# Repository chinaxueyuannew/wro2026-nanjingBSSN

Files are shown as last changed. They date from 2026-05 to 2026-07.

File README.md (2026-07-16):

# 南京博颂学校 | 2026 WRO Future Engineers 工程材料 / Engineering Materials

> 本页面所有内容均为中文与英文直接对照。 / All content on this page is presented directly in Chinese and English.

本仓库是 **南京博颂学校 / BONA SONORITY SCHOOL NANJING** 参加 2026 WRO Future Engineers 的公开工程材料，沿用官方 Future Engineers 模板，记录底盘、机电集成、Orange Pi视觉与GPIO/PWM直接控制、测试、安全分析、团队资料与演示视频。

This public repository documents the 2026 WRO Future Engineers project of **BONA SONORITY SCHOOL NANJING**. It follows the official Future Engineers template and records the chassis, mechatronic integration, Orange Pi vision with direct GPIO/PWM control, tests, safety analysis, team materials and demonstration video.

车辆以阿克曼四轮驱动底盘为机械基础，只使用 **USB彩色摄像头**进行环境感知。**Orange Pi Zero 3W 4GB**在同一平台上完成视觉、路径决策、安全状态管理和GPIO/PWM执行，直接控制转向舵机与电机驱动器。当前车辆不安装Arduino，不使用超声波，也不读取编码器。

The vehicle uses a four-wheel-drive Ackermann chassis and a **USB colour camera as its only environmental sensor**. An **Orange Pi Zero 3W 4GB** performs vision, path decisions, safety-state management and GPIO/PWM execution on the same platform, directly controlling the steering servo and motor driver. The current vehicle has no Arduino, ultrasonic sensing or encoder feedback.

## 演示视频 / Driving Video

### [▶ YouTube：2026 WRO Future Engineers | 南京博颂学校 | Autonomous Driving Demonstration](https://youtu.be/DJcxiJCEFdo)

南京博颂学校自动驾驶演示 / Autonomous driving demonstration (https://youtu.be/DJcxiJCEFdo)

视频详情、原片参数与版本记录见 [`video视频/video.md`](video视频/video.md)。

See [`video视频/video.md`](video视频/video.md) for video details, local-file specifications and version records.

## 队伍与赛事成果 / Team and Competition

### 南京博颂学校 / BONA SONORITY SCHOOL NANJING

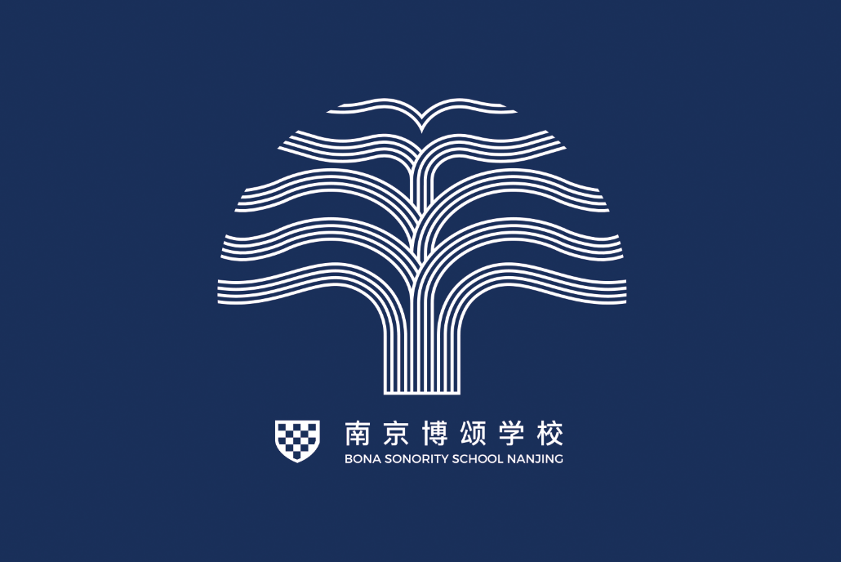
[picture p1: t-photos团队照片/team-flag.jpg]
南京博颂学校队旗 / School flag


我们围绕视觉无人驾驶阿克曼车辆开展程序、结构和电子系统协作。

We collaborate on programming, mechanical structure and electronics for a vision-based autonomous Ackermann vehicle.

| 姓名 / Name | 分工 / Role |
|---|---|
| 陆昭颖 / Lu Zhaoying | 程序 / Programming |
| 张隽泽 / Zhang Junze | 结构 / Mechanical Structure |
| 黄鸣博 / Huang Mingbo | 电子 / Electronics |
| 薛源 / Xue Yuan | 教练 / Coach |

[查看完整团队介绍 / Read the full team profile](other其他/team-profile.md) · [陆昭颖自我介绍（中/英/日） / Lu Zhaoying profile (CN/EN/JP)](other其他/team-profile.md#lu-zhaoying-profile)

### 成员照片 / Member Portraits

| 陆昭颖 / Lu Zhaoying | 张隽泽 / Zhang Junze | 黄鸣博 / Huang Mingbo |
|---|---|---|
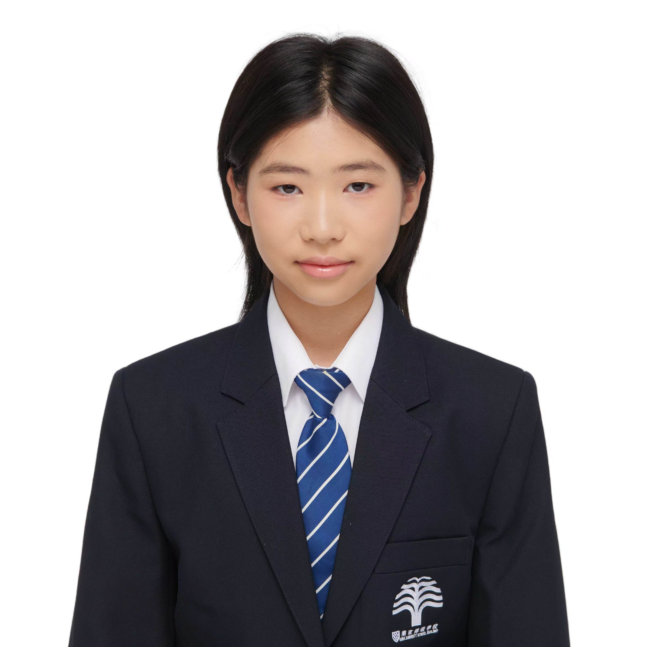
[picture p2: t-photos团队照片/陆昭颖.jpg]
陆昭颖，程序 / Lu Zhaoying, Programming
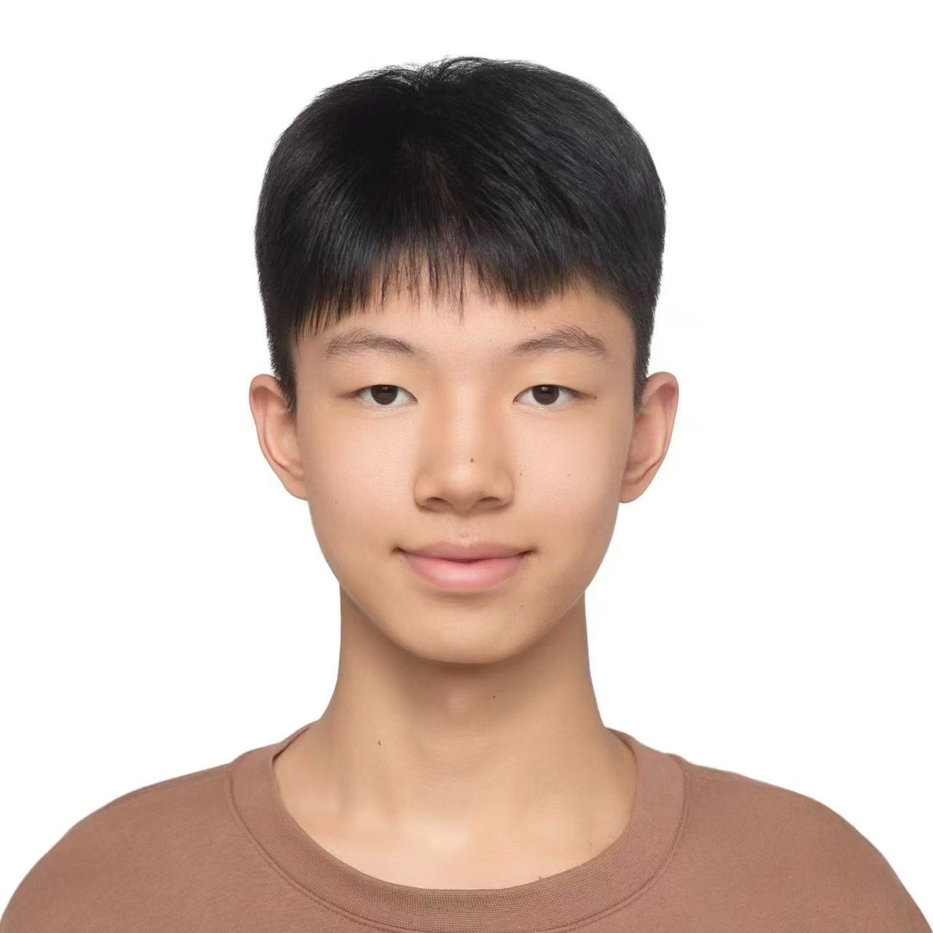
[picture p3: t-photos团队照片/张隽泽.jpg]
张隽泽，结构 / Zhang Junze, Mechanical Structure
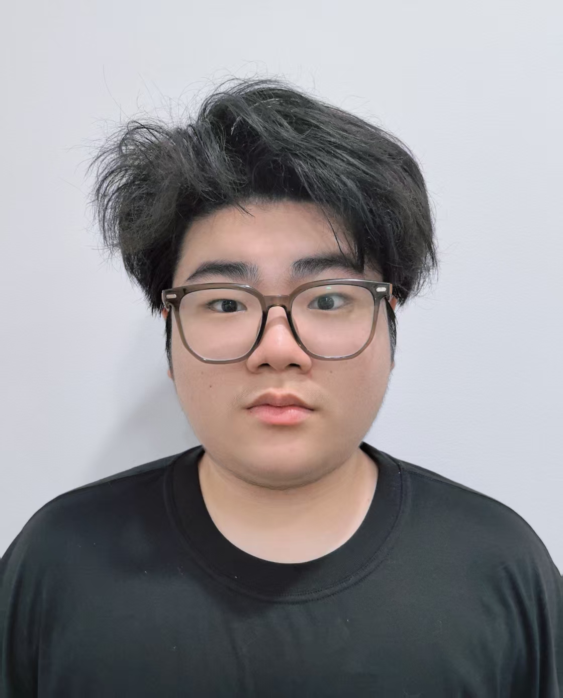
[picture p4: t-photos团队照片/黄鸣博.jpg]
黄鸣博，电子 / Huang Mingbo, Electronics
|  |  |  |

[陆昭颖形象照 / Additional portrait of Lu Zhaoying](t-photos团队照片/陆昭颖形象照.jpg)

### 正式团队照 / Official Team Photograph

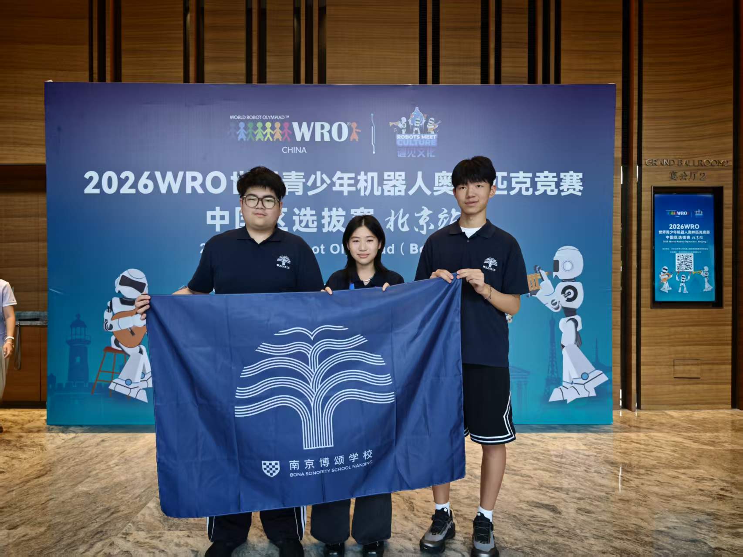
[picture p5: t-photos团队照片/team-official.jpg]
南京博颂学校WRO未来工程师参赛队 / WRO Future Engineers team


### 2026 WRO中国区选拔赛（北京站）未来工程师无人驾驶冠军 / 2026 WRO China Qualification Tournament (Beijing) Future Engineers Autonomous Driving Champion

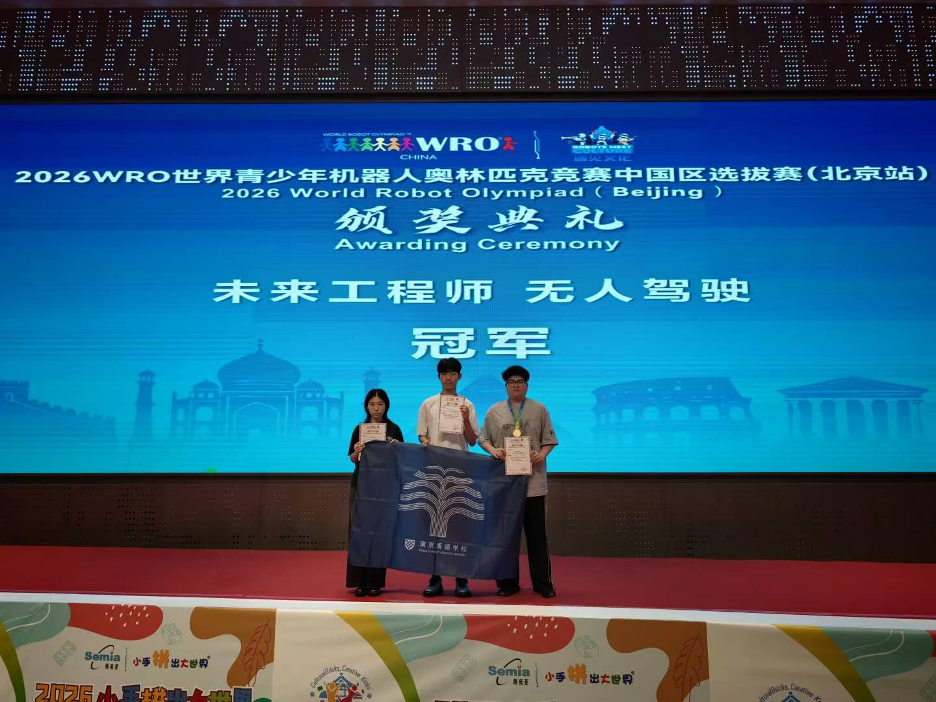
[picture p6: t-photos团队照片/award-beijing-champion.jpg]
北京站冠军领奖照片 / Beijing championship award photograph


### 车辆比赛现场 / Vehicle on the Competition Field

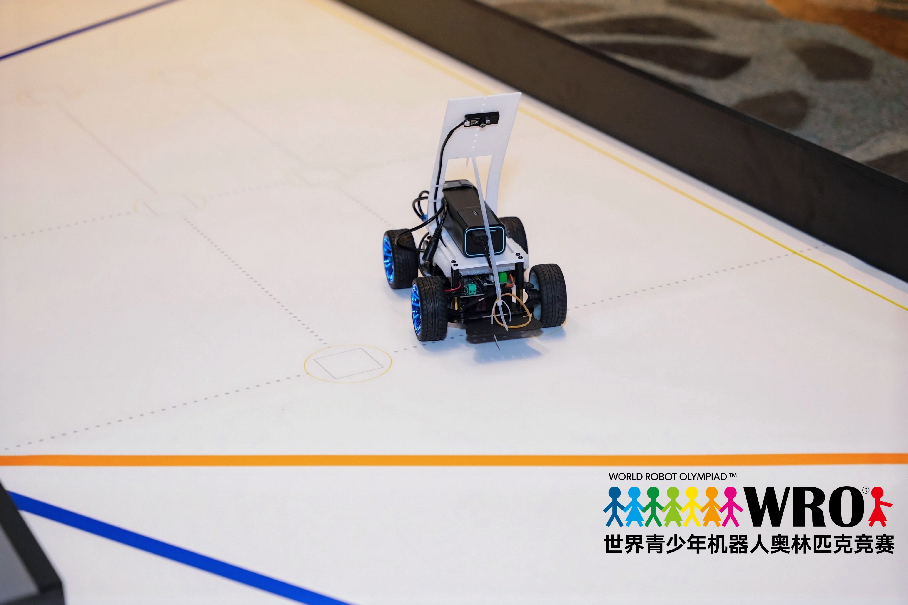
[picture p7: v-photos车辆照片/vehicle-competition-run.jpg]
车辆比赛现场 / Vehicle on the competition field


更多研发记录见[制作过程照片索引](t-photos团队照片/README.md)。车辆标准六视图仍待补充。

See the [development-process photo index](t-photos团队照片/README.md) for more records. The standard six-view vehicle photographs are still pending.

## 快速跳转 / Quick Navigation

- [2026五维评分证据地图 / 2026 rubric evidence map](other其他/scoring-evidence.md) · [可归档工程日志PDF / Archival engineering-log PDF](other其他/engineering-log.pdf) · [实测与照片证据登记 / Evidence register](other其他/evidence-register.md)
- [团队介绍 / Team profile](other其他/team-profile.md) · [系统概述 / System overview](#2-系统概述--system-overview) · [机械设计 / Mechanical design](#3-移动性与机械设计--mobility-and-mechanical-design) · [动力与视觉 / Power and vision](#4-动力与视觉架构--power-and-vision-architecture)
- [源代码 / Source code](src源代码/README.md) · [接线与供电 / Wiring and power](schemes原理图/wiring.md) · [正式PNG接线图 / Formal PNG wiring diagram](schemes原理图/system-wiring.png) · [机械模型 / Mechanical models](models模型/README.md) · [物料表 / BOM](other其他/BOM.md)
- [测试 / Tests](other其他/tests.md) · [工程日志 / Engineering log](other其他/engineering-log.md) · [FMEA](other其他/FMEA.md) · [比赛检查表 / Competition checklist](other其他/competition-checklist.md)
- [团队照片 / Team photos](t-photos团队照片/README.md) · [车辆照片 / Vehicle photos](v-photos车辆照片/README.md) · [视频 / Video](video视频/video.md) · [完整索引 / Complete index](#10-完整文件索引--complete-file-index)

## 当前成果状态 / Current Project Status

| 项目 / Item | 仓库状态 / Repository Status | 验证状态 / Validation Status |
|---|---|---|
| 阿克曼底盘 / Ackermann chassis | 已有机械说明和层板DXF / Mechanical description and plate DXF included | 现有规格记录已整理，最终装车尺寸待测 / Existing specification record documented; final assembled dimensions pending |
| 超声波与编码器代码 / Ultrasonic and encoder code | 团队早期自主实验代码已入库 / Earlier team-developed experimental code included | 当前车辆不使用 / Not used by the current vehicle |
| 道路预处理 / Road preprocessing | `bev_road.py` 已入库 / Included | 透视参数仍需实车标定 / Perspective parameters require vehicle calibration |
| 红绿视觉控制 / Red-green vision control | `bev_segmentation.py` 已入库 / Included | 当前主要方向，仍需板端和实车验证 / Current main approach; board and vehicle validation pending |
| Orange Pi GPIO/PWM执行 / Orange Pi GPIO/PWM execution | `orange_pi_gpio.py`、安全状态机和配置模板已入库 / Driver, safety state machine and configuration template included | 默认禁用、上电停车、物理按钮、限幅、退出清零和250 ms进程看门狗已闭环；实际GPIO/PWM映射及硬件测试待完成 / Disabled-by-default, power-on stop, physical button, limits, zero-on-exit and 250 ms process watchdog implemented; actual mapping and hardware tests pending |
| 接线与配电 / Wiring and distribution | 现行GPIO直控PNG/SVG、供电分支和映射表已入库 / Current direct-GPIO PNG/SVG, power branches and mapping table included | 实际GPIO line、PWM chip/channel、逻辑电平、额定值和支路电流待实物核验 / Actual GPIO lines, PWM chip/channels, logic levels, ratings and branch currents require physical verification |
| 评分与工程日志 / Rubric and engineering log | 五维证据地图、缺失证据登记、双语PDF已入库 / Five-dimension map, gap register and bilingual PDF included | 实测后需更新PDF和签署 / PDF and sign-off require update after measurements |
| 驾驶演示 / Driving demonstration | YouTube链接和87.07 MiB视频已入库 / YouTube link and 87.07 MiB video included | 拍摄日期、提交号和硬件对应表待补 / Date, commit and hardware mapping pending |
| 团队材料 / Team materials | 队旗、介绍、三名成员照、正式照、冠军照和11张过程照已入库 / Flag, profile, three portraits, official photo, award photo and 11 process photos included | 趣味团队照待补 / Informal team photo pending |
| 车辆照片 / Vehicle photos | 比赛现场照片和六视图规范已入库 / Competition photo and six-view specification included | 标准六视图待补 / Standard six views pending |

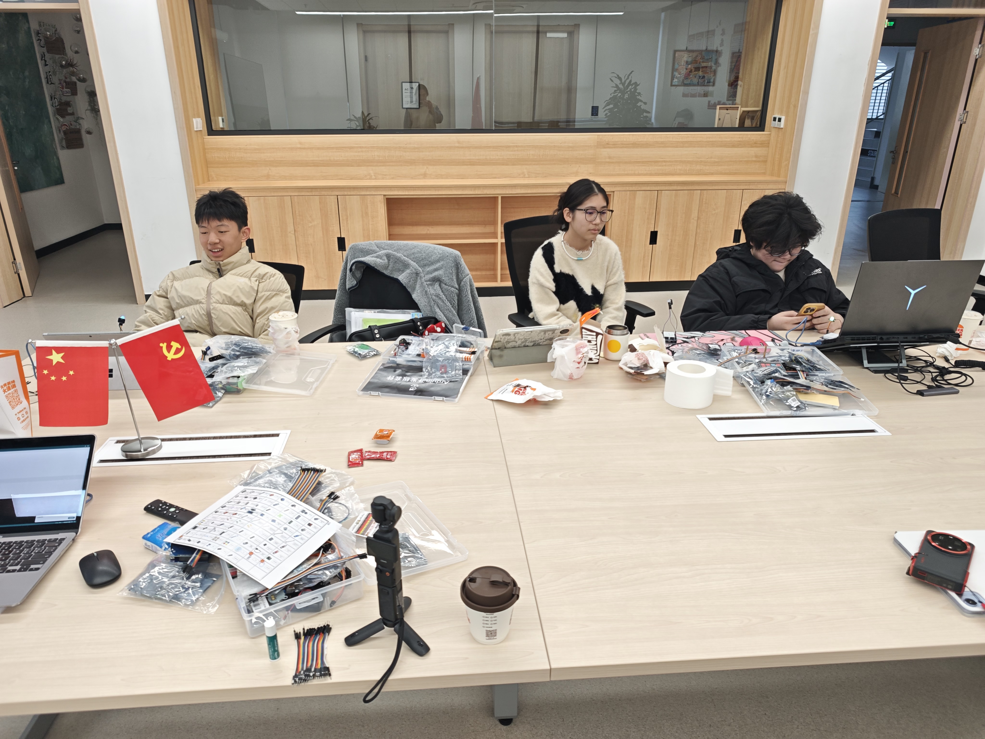
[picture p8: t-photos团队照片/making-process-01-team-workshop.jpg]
团队制作过程 / Team development process


## 1. 仓库导航 / Repository Navigation

| 目录或文件 / Folder or File | 内容 / Contents | 复现用途 / Reproduction Use |
|---|---|---|
| [`README.md`](README.md) | 总体技术说明、视频、状态和导航 / Overall documentation, video, status and navigation | 裁判首页与总体复现 / Landing page and system reproduction |
| [`src源代码/`](src源代码/README.md) | Orange Pi视觉、GPIO/PWM执行与历史实验 / Orange Pi vision, GPIO/PWM execution and historical experiments | 编译、运行和算法审查 / Build, execution and algorithm review |
| [`schemes原理图/`](schemes原理图/wiring.md) | GPIO/PWM映射、供电和接线 / GPIO/PWM mapping, power and wiring | 电气复现 / Electrical reproduction |
| [`models模型/`](models模型/README.md) | 底盘、尺寸和层板DXF / Chassis, dimensions and plate DXF | 机械复现 / Mechanical reproduction |
| [`other其他/`](other其他/engineering-log.md) | 物料、测试、标定、风险和日志 / BOM, tests, calibration, risk and logs | 工程追溯 / Engineering traceability |
| [`t-photos团队照片/`](t-photos团队照片/README.md) | 团队、赛事和制作过程照片 / Team, competition and development photos | 团队与过程证据 / Team and process evidence |
| [`v-photos车辆照片/`](v-photos车辆照片/README.md) | 比赛照片和六视图规范 / Competition photo and six-view specification | 车辆与布线检查 / Vehicle and wiring inspection |
| [`video视频/`](video视频/video.md) | YouTube链接和本地视频参数 / YouTube link and local video specifications | 驾驶证明与版本追溯 / Driving evidence and version traceability |

### 详细工程文件 / Detailed Engineering Documents

- [物料表与选型依据 / Bill of materials and selection](other其他/BOM.md)
- [2026评分证据地图 / 2026 scoring-evidence map](other其他/scoring-evidence.md)
- [实测与照片证据登记 / Measurement and photograph evidence register](other其他/evidence-register.md)
- [源代码、运行方法与验证状态 / Source code, operation and validation](src源代码/README.md)
- [GPIO/PWM接线与供电 / GPIO/PWM wiring and power](schemes原理图/wiring.md)
- [正式PNG接线图 / Formal PNG wiring diagram](schemes原理图/system-wiring.png)
- [机械模型、尺寸与DXF / Mechanical models, dimensions and DXF](models模型/README.md)
- [Orange Pi车载计算平台 / Orange Pi onboard computer](other其他/processor-orange-pi.md)
- [摄像头与视觉方案 / Camera and vision](other其他/camera-vision.md)
- [机械分析 / Mechanical analysis](other其他/mechanical-analysis.md)
- [软件架构 / Software architecture](other其他/software-architecture.md)
- [标定手册 / Calibration guide](other其他/calibration-guide.md)
- [风险分析 / Risk analysis](other其他/FMEA.md)
- [复现指南 / Reproduction guide](other其他/reproduction-guide.md)
- [工程日志Markdown / Engineering log in Markdown](other其他/engineering-log.md) · [可归档PDF / Archival PDF](other其他/engineering-log.pdf)
- [工程日志PDF生成脚本 / Engineering-log PDF build script](other其他/build_engineering_log_pdf.py)
- [团队介绍 / Team profile](other其他/team-profile.md)
- [比赛检查表 / Competition checklist](other其他/competition-checklist.md)
- [测试流程 / Test procedure](other其他/tests.md)
- [版本记录 / Changelog](other其他/CHANGELOG.md)

## 2. 系统概述 / System Overview

车辆采用汽车式阿克曼转向和四轮机械驱动。四根转向拉杆将舵机动作传到左右转向节；前后差速器和中间传动轴驱动车轮。底盘电机带有霍尔编码器接口，但当前车辆不接线、不读取，也不进行闭环速度控制。

The vehicle uses automotive-style Ackermann steering and mechanical four-wheel drive. Four steering links transfer servo motion to the left and right steering knuckles. Front and rear differentials and a longitudinal shaft drive the wheels. The motors provide Hall-encoder interfaces, but the current vehicle does not connect or read them and does not use closed-loop speed control.

底盘规格为 **260 × 140 × 85 mm**；去除防撞棉后主体长度约 **246 mm**。轴距 **174 mm**，轮距 **123 mm**，轮径 **47 mm**，离地间隙 **6 mm**，基础重量约 **0.7 kg**，标称负载 **0.3 kg**，最小转弯半径 **475 mm**。安装全部设备后必须重新实测。

The documented chassis size is **260 × 140 × 85 mm**, or approximately **246 mm** long without the foam bumpers. Wheelbase is **174 mm**, track width **123 mm**, wheel diameter **47 mm**, ground clearance **6 mm**, base mass approximately **0.7 kg**, rated additional load **0.3 kg**, and minimum turning radius **475 mm**. All values must be measured again after final assembly.

```mermaid
flowchart LR
  CAM["USB彩色摄像头 / USB colour camera"] --> OPI["Orange Pi Zero 3W 4GB"]
  OPI -->|"视觉与决策 / Vision and decisions"| SAFE["GPIO安全状态机 / GPIO safety state machine"]
  SAFE -->|"PWM（映射待冻结） / PWM mapping pending"| SERVO["转向舵机 / Steering servo"]
  SAFE -->|"PWM + DIR（映射待冻结） / mapping pending"| DRIVER["电机驱动器 / Motor driver"]
  BUTTON["物理启动/停止按钮 / Physical start-stop"] -->|"3.3 V GPIO input"| SAFE
  DRIVER --> MOTOR["四轮驱动 / Four-wheel drive"]
  BAT["车载电源 / Vehicle battery"] --> REG["稳压与配电 / Regulation and distribution"]
  REG --> OPI
  REG --> SERVO
  REG --> DRIVER
```

当前感知输入只有USB摄像头。视觉帧过期、控制更新过期、程序异常或退出时，Orange Pi输出层必须立即把电机占空比置零并使舵机回中；250 ms进程看门狗触发后必须重新按键授权。该进程级机制不能覆盖Linux内核或硬件PWM整体冻结，因此最终安全评估仍需验证是否增加独立硬件使能门。

The USB camera is the only perception input. On stale frames, stale control updates, exceptions or process exit, the Orange Pi output layer must immediately command zero motor duty and centred steering; a 250 ms process-watchdog event requires physical re-arming. This process-level mechanism cannot cover a complete Linux-kernel or hardware-PWM freeze, so the final safety assessment must determine whether an independent hardware enable gate is required.

## 3. 移动性与机械设计 / Mobility and Mechanical Design

### 3.1 底盘方案 / Chassis Concept

选择阿克曼底盘是因为其运动方式接近真实汽车，直线稳定、转弯轨迹连续且轮胎侧滑较小。代价是转弯半径受轴距和最大转角限制，必须准确标定舵机中位、左右极限和转向连杆。

The Ackermann chassis was selected because its motion resembles a real car, with stable straight-line travel, continuous turning paths and reduced tyre scrub. The trade-off is a turning radius limited by wheelbase and maximum steering angle, so servo centre, left/right limits and steering links require careful calibration.

差速器允许转弯时内外侧车轮以不同速度滚动。最终文档仍需补充实车传动照片、齿数、电机标牌和完整装配尺寸。

The differentials allow inner and outer wheels to rotate at different speeds during a turn. Final documentation still requires drivetrain photographs, gear counts, motor labels and complete assembled dimensions.

### 3.2 转向保护 / Steering Protection

历史程序曾把逻辑转向量 `-100...100` 映射到约 `35...145°`。当前GPIO/PWM输出层为降低首次集成风险，默认使用更保守的舵机脉宽范围与中位脉宽；这些都不是最终装车结论。必须架空实测左右机械安全极限并留出余量，更换舵机、舵臂孔位或拉杆长度后必须重新标定。

Historical sketches mapped logical steering `-100...100` to approximately `35...145°`. To reduce first-integration risk, the current GPIO/PWM output layer uses a conservative default pulse-width range and centre pulse. These are not final assembled-vehicle results; measure both mechanical limits with the wheels lifted and retain margin. Recalibrate after changing the servo, horn position or link length.

### 3.3 速度、扭矩与几何 / Speed, Torque and Geometry

规格图给出47 mm轮径、1:8.864齿轮速比、1692 rpm车轮转速、12 V参考速度3.5 m/s、1.9 A额定电流、22.8 W额定功率和10 kg·cm舵机扭矩。

The catalogue lists a 47 mm wheel diameter, 1:8.864 gear ratio, 1692 rpm wheel speed, 3.5 m/s reference speed at 12 V, 1.9 A rated current, 22.8 W rated power and 10 kg·cm servo torque.

- 理论车速 / Theoretical speed：`v = π × D × n_motor / (60 × i)`
- 轮端扭矩 / Wheel torque：`T_wheel = T_motor × i × η`
- 牵引力 / Traction：`F = T_wheel / (D/2)`
- 阿克曼半径 / Ackermann radius：由轴距、轮距和内轮转角计算，并用地面画圆验证 / calculated from wheelbase, track and inner-wheel angle, then verified by a measured ground circle

1692 rpm按47 mm轮径换算约4.17 m/s，高于3.5 m/s参考值，可能分别是理论空载值和实际参考值，因此两者均保留并要求实测。

At a 47 mm wheel diameter, 1692 rpm converts to approximately 4.17 m/s, above the 3.5 m/s reference. These may represent theoretical no-load and practical reference values respectively, so both are retained and require measurement.

## 4. 动力与视觉架构 / Power and Vision Architecture

### 4.1 控制器与执行器 / Controllers and Actuators

Orange Pi负责摄像头、OpenCV图像处理、赛道判断、红绿障碍策略、安全状态机以及GPIO/PWM输出。它通过内核PWM直接控制舵机和电机速度，通过3.3 V GPIO控制电机方向并读取物理启动/停止按钮。实际GPIO line和PWM chip/channel必须依据冻结的比赛系统镜像、设备树与实物排针核对后填写，文档不虚构引脚号。

The Orange Pi handles the camera, OpenCV processing, track interpretation, red/green obstacle strategy, safety state machine and GPIO/PWM output. Kernel PWM directly controls steering and motor speed; 3.3 V GPIO controls motor direction and reads the physical start/stop button. Actual GPIO lines and PWM chip/channel values must be filled only after checking the frozen competition image, device tree and physical header; this documentation does not invent pin numbers.

舵机和电机不得由Orange Pi排针供电。应使用电机动力支路、Orange Pi独立5 V/3 A稳压支路和舵机独立支路，并保持控制共地。连接驱动器前必须确认其逻辑输入兼容3.3 V；不兼容时使用合适的电平转换或接口电路。

The servo and motor must not be powered from the Orange Pi header. Use a motor-power branch, an independent regulated 5 V/3 A Orange Pi branch and a separate servo branch, with a common control ground. Confirm 3.3 V compatibility before connecting the driver; otherwise use an appropriate level shifter or interface circuit.

### 4.2 视觉感知 / Vision Perception

车辆只安装一个USB彩色摄像头，不安装超声波，也不读取编码器。团队采购记录中的版本为 **160°广角有畸变、30 FPS彩色、非夜视、480p**，并记录GC0308、HBVCAM、CMOS、30万像素和USB免驱。彩色画面用于区分红绿障碍；广角畸变通过标定、ROI裁剪和现场光照测试处理。

The vehicle uses one USB colour camera, with no ultrasonic sensors and no encoder readings. The team purchase record identifies a **160° distorted wide angle, 30 FPS colour, non-night-vision and 480p** version and records GC0308, HBVCAM, CMOS, 0.3 megapixels and driver-free USB. Colour frames distinguish red and green obstacles; wide-angle distortion is handled through calibration, ROI cropping and on-site lighting tests.

安全措施包括配置默认禁用、上电默认停车、视觉帧超时、250 ms控制更新看门狗、程序退出清零PWM、物理启动/停止控制、方向切换前先归零电机以及最坏停车距离测试。

Safety measures include disabled-by-default configuration, stopped-by-default power-up, vision-frame timeout, a 250 ms control-update watchdog, zero PWM on exit, physical start/stop control, zero motor duty before direction changes and worst-case stopping-distance tests.

### 4.3 动力预算 / Power Budget

总峰值电流应按下式估算，并用实车电流数据替换目录值：

Total peak current should be estimated with the following expression and updated using measured vehicle data:

`I_peak = I_motor_start + I_servo_stall + I_orange_pi_camera + I_controller + safety_margin`

测试应记录静止、视觉运行、直行、最大转向和电机启动时的电池电压与电流。复位、摄像头断连或掉帧时，应检查稳压余量、共地、电机噪声和线束压降。

Tests must record battery voltage and current while idle, running vision, travelling straight, steering fully and starting the motor. If a controller resets or the camera disconnects or drops frames, check regulator margin, common ground, motor noise and wiring voltage drop.

## 5. 软件架构与控制策略 / Software Architecture and Control Strategy

### 5.1 当前程序 / Current Programs

| 层级 / Layer | 程序 / Program | 内容 / Function | 状态 / Status |
|---|---|---|---|
| 历史巡墙基线 / Historical wall-follow baseline | [`main1.0.ino`](src源代码/main1.0/main1.0.ino) | 双超声波P控制 / Dual-ultrasonic P control | 当前不使用 / Not currently used |
| 团队早期实验 / Earlier team experiments | [`UNO_AT8236`](src源代码/UNO_AT8236_OpenChallenge/UNO_AT8236_OpenChallenge.ino), [`UNO_DRV8701`](src源代码/UNO_DRV8701_OpenChallenge/UNO_DRV8701_OpenChallenge.ino) | 编码器PI和双超声波 / Encoder PI and dual ultrasonic | 团队自主开发，当前不使用 / Team-developed; not currently used |
| ESP32试验 / ESP32 experiment | [`ESP32_AT8236`](src源代码/ESP32_AT8236_OpenChallenge/ESP32_AT8236_OpenChallenge.ino) | AT8236控制和关闭无线 / AT8236 control and wireless shutdown | 仅参考 / Reference only |
| 道路工具 / Road tool | [`bev_road.py`](src源代码/bev_road.py) | 亮度、BEV、道路掩膜和连通域 / Brightness, BEV, road mask and components | 需实车标定 / Vehicle calibration required |
| 视觉与策略 / Vision and strategy | [`bev_segmentation.py`](src源代码/bev_segmentation.py) | 红绿识别、方向策略、恢复和GPIO输出调用 / Red-green detection, direction strategy, recovery and GPIO-output calls | 当前主要方向 / Current main approach |
| Orange Pi GPIO/PWM执行 / Orange Pi GPIO/PWM execution | [`orange_pi_gpio.py`](src源代码/orange_pi_gpio.py) | 物理按钮、PWM/DIR输出、限幅、250 ms看门狗和安全释放 / Physical button, PWM/DIR output, limits, 250 ms watchdog and safe release | 语法通过；实际映射和实车验证待完成 / Syntax passed; actual mapping and vehicle validation pending |
| 上一版串口执行 / Previous serial executor | [`VisionSerialExecutor.ino`](src源代码/VisionSerialExecutor/VisionSerialExecutor.ino) | Arduino串口执行架构的历史记录 / Historical record of the Arduino serial-execution architecture | 当前不安装、不运行 / Not installed or run currently |

当前三份Python核心文件已通过语法解析。视觉程序默认速度为0，减速阈值低于避障阈值，制动阶段先停车，并在视频源丢失或程序退出时调用安全停止。`orange_pi_gpio.py`将直接硬件访问集中在一个输出层：配置默认 `enabled=false`，只有填写并核验真实映射后才打开GPIO/PWM；上电进入 `WAIT_START`，由物理按钮授权，250 ms无新控制更新进入 `CONTROL_FAILSAFE`，异常或退出时电机归零、舵机回中并释放资源。该实现仍需在冻结系统镜像上完成设备树、PWM占用、3.3 V逻辑兼容性、输出波形和整车停车测试。

The three current core Python files pass syntax parsing. The vision controller defaults to zero speed, keeps the slow-down threshold below the avoidance threshold, stops before recovery braking and invokes a safe stop on video loss or process exit. `orange_pi_gpio.py` centralises direct hardware access in one output layer: `enabled=false` is the default, GPIO/PWM is opened only after real mappings are entered and verified, power-up enters `WAIT_START`, a physical button arms motion, no fresh control update for 250 ms enters `CONTROL_FAILSAFE`, and exceptions or exit zero the motor, centre steering and release resources. Device-tree exposure, PWM ownership, 3.3 V logic compatibility, output waveforms and full-vehicle stopping still require verification on the frozen competition image.

历史Arduino程序中的 `getDistance()`、`move()`、`steer()`、`setup()` 和 `loop()` 仅用于解释早期硬件验证，不代表当前传感器配置。

The `getDistance()`, `move()`, `steer()`, `setup()` and `loop()` functions in historical Arduino programs document early hardware validation only and do not represent the current sensor configuration.

### 5.2 历史巡墙控制 / Historical Wall-Following Control

早期程序使用目标右距30 cm、`KP=2.5`和速度70的P控制。该方案计算量小，但不能识别颜色，也缺少积分和微分作用。它仅作为研发历史保留。

The early program used a 30 cm target right-wall distance, `KP=2.5` and speed 70. It was computationally simple but could not identify colours and had no integral or derivative action. It is retained only as development history.

### 5.3 当前边界与升级 / Current Boundaries and Upgrades

当前版本不使用板间串口。视觉策略在同一进程内调用受限的GPIO/PWM输出接口，并以单调时钟记录最近一次控制更新；物理启动和250 ms进程级失效停车已在代码中实现。透视、HSV、道路密度、红绿通过侧、倒车时间、速度、实际GPIO/PWM映射、停车区、圈数、方向初始化、无桌面自动启动/恢复和多光照长时间测试仍需完成。由于视觉与执行位于同一Orange Pi，Linux或硬件PWM整体冻结是尚未由进程看门狗覆盖的残余风险。

The current version has no inter-board serial link. The vision strategy calls a bounded GPIO/PWM output interface in the same process, using a monotonic clock for the latest control update; physical arming and a 250 ms process-level fail-safe are implemented in code. Perspective, HSV, road density, red/green passing side, reversing time, speed, actual GPIO/PWM mapping, parking, lap counting, direction initialisation, headless startup/recovery and long-duration multi-lighting tests remain incomplete. Because vision and execution share one Orange Pi, a complete Linux or hardware-PWM freeze remains outside the process watchdog's coverage.

## 6. 系统思维与工程决策 / System Thinking and Engineering Decisions

1. **阿克曼转向 / Ackermann steering：** 更接近汽车并提高直线稳定性，但需要更精确的机械标定。 / More automotive and stable in straight travel, but requires more precise mechanical calibration.
2. **历史超声波基线 / Historical ultrasonic baseline：** 曾用于验证底盘、舵机和电机方向；当前只保留代码，不作为比赛传感器或安全备份。 / Previously validated chassis, servo and motor direction; retained only as code history, not as a competition sensor or safety backup.
3. **视觉失效停车 / Stop on vision failure：** 无独立距离传感器时，视觉帧或控制更新超时必须立即把电机PWM置零并要求重新授权。 / Without an independent range sensor, a vision-frame or control-update timeout must immediately set motor PWM to zero and require re-arming.
4. **单板直控取舍 / Single-board direct-control trade-off：** 取消Arduino和串口可减少器件、线束与协议延迟，但视觉、决策和执行进入同一故障域，因此必须明确进程看门狗的边界并评估独立硬件使能保护。 / Removing the Arduino and serial link reduces parts, wiring and protocol latency, but places vision, decision and execution in one fault domain; the process-watchdog boundary and an independent hardware enable must therefore be assessed explicitly.

## 7. 搭建、编译与上传 / Assembly, Build and Upload

1. 按[机械文档](models模型/README.md)固定底盘、Orange Pi、电源、摄像头、舵机和支架；当前车辆不安装Arduino。 / Mount the chassis, Orange Pi, power system, camera, servo and brackets according to the [mechanical documentation](models模型/README.md); the current vehicle has no Arduino.
2. 在冻结的比赛镜像上列出 `/dev/gpiochip*` 与 `/sys/class/pwm`，对照排针和设备树确认真实GPIO line、PWM chip/channel及复用关系。 / On the frozen competition image, enumerate `/dev/gpiochip*` and `/sys/class/pwm`, then confirm real GPIO lines, PWM chip/channels and pin multiplexing against the header and device tree.
3. 按[接线文档](schemes原理图/wiring.md)连接摄像头、物理按钮、舵机与电机驱动器；先确认3.3 V逻辑兼容并保持负载独立供电与控制共地。 / Follow the [wiring guide](schemes原理图/wiring.md) for the camera, physical button, servo and motor driver; verify 3.3 V logic compatibility and keep load power separate with a common control ground.
4. 安装并冻结Python、OpenCV、NumPy和python-periphery依赖，把 [`gpio_config.example.json`](src源代码/gpio_config.example.json) 复制为本地 `gpio_config.json`，核验后再把 `enabled` 设为 `true`。 / Install and freeze Python, OpenCV, NumPy and python-periphery, copy [`gpio_config.example.json`](src源代码/gpio_config.example.json) to local `gpio_config.json`, and set `enabled` to `true` only after verification.
5. 保持 `enabled=false` 用录像测试视觉与DRY_RUN输出，确认默认速度为0、方向与红绿策略正确。 / Keep `enabled=false` while testing vision and DRY_RUN output from recordings; confirm zero default speed and correct direction and red/green strategy.
6. 抬轮执行G-01至G-10，测量PWM频率、占空比、舵机脉宽、方向切换死区和250 ms看门狗停车时间。 / With the wheels lifted, perform G-01 through G-10 and measure PWM frequency, duty cycle, steering pulse widths, direction-change dead time and the 250 ms watchdog stop time.
7. 从低速开始测试直行、弯道、障碍、摄像头断开、进程终止、重启和30分钟稳定性。 / Starting at low speed, test straight travel, turns, obstacles, camera loss, process termination, restart and 30-minute stability.
8. 在[测试记录](other其他/tests.md)中保存日期、提交号、镜像版本、映射、参数和结果。 / Record date, commit, image version, mapping, parameters and results in the [test records](other其他/tests.md).

## 8. 测试、风险与版本管理 / Testing, Risk and Version Management

主要风险包括舵机顶死、电机启动压降、视觉误判或掉帧、摄像头断开、GPIO/PWM映射错误、3.3 V逻辑不兼容、Linux或PWM冻结、转向符号错误、线束松脱、轮胎打滑、上电即行驶和无线通信未关闭。每次上场前应完成静态、抬轮、低速和完整回合测试。

Main risks include servo mechanical stall, motor-start voltage drop, visual misclassification or dropped frames, camera disconnection, incorrect GPIO/PWM mapping, incompatible 3.3 V logic, a Linux or PWM freeze, reversed steering sign, loose wiring, tyre slip, movement immediately after power-up and wireless communication left enabled. Complete static, lifted-wheel, low-speed and full-lap tests before every run.

后续提交说明应可追溯，例如 `docs: add measured power budget`、`vision: tune obstacle HSV from field data` 和 `hardware: add final wiring diagram`。公开仓库应按规则保持可访问。

Future commit messages should be traceable, for example `docs: add measured power budget`, `vision: tune obstacle HSV from field data` and `hardware: add final wiring diagram`. The public repository must remain accessible as required by the rules.

## 9. 提交前缺口清单 / Pre-Submission Gap Checklist

- [x] 公开YouTube驾驶演示 / Public YouTube driving demonstration.
- [x] Orange Pi视觉/GPIO直控程序、配置模板以及上一版本Arduino/ESP32实验记录 / Orange Pi vision/direct-GPIO code, configuration template and previous Arduino/ESP32 experiment records.
- [x] DXF、BOM、接线、风险、标定、测试和复现资料 / DXF, BOM, wiring, risk, calibration, test and reproduction materials.
- [x] 2026五维评分地图、缺失证据登记和结构化双语工程日志PDF / 2026 five-dimension map, missing-evidence register and structured bilingual engineering-log PDF.
- [x] Orange Pi GPIO/PWM安全输出层与现行PNG/SVG接线图 / Orange Pi GPIO/PWM safety-output layer and current PNG/SVG wiring diagram.
- [x] 正式团队照、冠军照和比赛现场车辆照 / Official team, championship and competition-field vehicle photographs.
- [ ] 补充车辆前、后、左、右、顶、底六视图 / Add front, rear, left, right, top and bottom vehicle views.
- [ ] 补充全员趣味照 / Add an informal full-team photograph.
- [ ] 在视频文档填写拍摄日期、提交号和硬件参数 / Add recording date, commit and hardware parameters to the video document.
- [ ] 补充最终CAD/STL、传动参数和摄像头安装尺寸 / Add final CAD/STL, drivetrain data and camera mounting dimensions.
- [ ] 以实物核验PNG电路图中的准确器件型号、额定值、逻辑电平、保险和引脚 / Physically verify exact models, ratings, logic levels, fuse and pins in the PNG diagram.
- [ ] 完成尺寸、质量、速度、电流、转弯半径和完整回合实测 / Measure dimensions, mass, speed, current, turning radius and full-lap time.
- [ ] 验证物理启动、视觉/控制更新超时停车、Linux/PWM冻结边界并关闭无线 / Verify physical start, vision/control-update timeout stopping, Linux/PWM freeze boundary and disabled wireless functions.
- [ ] 完成透视、红绿识别、圈数、停车区和停车策略 / Complete perspective, red-green detection, lap counting, parking zone and stopping strategy.

## 10. 完整文件索引 / Complete File Index

### 程序与配置 / Programs and Configuration

| 文件 / File | 内容 / Contents |
|---|---|
| [`src源代码/README.md`](src源代码/README.md) | 运行、依赖、安全和验证状态 / Operation, dependencies, safety and validation status |
| [`main1.0.ino`](src源代码/main1.0/main1.0.ino) | 历史超声波巡墙 / Historical ultrasonic wall following |
| [`UNO_AT8236`](src源代码/UNO_AT8236_OpenChallenge/UNO_AT8236_OpenChallenge.ino) | UNO + AT8236历史参考 / Historical reference |
| [`UNO_DRV8701`](src源代码/UNO_DRV8701_OpenChallenge/UNO_DRV8701_OpenChallenge.ino) | UNO + DRV8701历史参考 / Historical reference |
| [`ESP32_AT8236`](src源代码/ESP32_AT8236_OpenChallenge/ESP32_AT8236_OpenChallenge.ino) | ESP32试验参考 / ESP32 experimental reference |
| [`bev_road.py`](src源代码/bev_road.py) | 道路掩膜和BEV调试 / Road mask and BEV debugging |
| [`bev_segmentation.py`](src源代码/bev_segmentation.py) | 红绿视觉、方向策略、恢复和GPIO输出调用 / Red-green vision, direction strategy, recovery and GPIO output calls |
| [`orange_pi_gpio.py`](src源代码/orange_pi_gpio.py) | 现行GPIO/PWM输出、安全状态和250 ms进程看门狗 / Current GPIO/PWM output, safety states and 250 ms process watchdog |
| [`gpio_config.example.json`](src源代码/gpio_config.example.json) | 默认禁用的GPIO/PWM配置模板 / Disabled-by-default GPIO/PWM configuration template |
| [`VisionSerialExecutor.ino`](src源代码/VisionSerialExecutor/VisionSerialExecutor.ino) | 上一版本Arduino串口执行记录 / Previous Arduino serial-executor record |
| [`requirements.txt`](src源代码/requirements.txt) | Python依赖 / Python dependencies |
| [`serial_config.example.json`](src源代码/serial_config.example.json) | 上一版本串口配置记录 / Previous-version serial configuration record |

### 机械、电气与工程文档 / Mechanical, Electrical and Engineering Documents

| 文件 / File | 内容 / Contents |
|---|---|
| [`models模型/README.md`](models模型/README.md) | 底盘、尺寸和模型 / Chassis, dimensions and models |
| [`HSP94182层板.dxf`](models模型/HSP94182层板.dxf) | 二维层板文件 / 2D plate file |
| [`wiring.md`](schemes原理图/wiring.md) | GPIO/PWM映射、供电和接线 / GPIO/PWM mapping, power and wiring |
| [`system-wiring.png`](schemes原理图/system-wiring.png) / [`SVG`](schemes原理图/system-wiring.svg) | 双语系统接线图与可编辑矢量源 / Bilingual system wiring and editable vector source |
| [`BOM.md`](other其他/BOM.md) | 物料与选型 / Materials and selection |
| [`processor-orange-pi.md`](other其他/processor-orange-pi.md) | Orange Pi规格、职责和验收 / Orange Pi specifications, role and acceptance |
| [`camera-vision.md`](other其他/camera-vision.md) | 摄像头、安装、标定和指标 / Camera, mounting, calibration and metrics |
| [`mechanical-analysis.md`](other其他/mechanical-analysis.md) | 几何、速度和机械分析 / Geometry, speed and mechanical analysis |
| [`software-architecture.md`](other其他/software-architecture.md) | 架构、状态机和数据流 / Architecture, state machine and data flow |
| [`calibration-guide.md`](other其他/calibration-guide.md) | 舵机、摄像头、速度和转向标定 / Servo, camera, speed and steering calibration |
| [`FMEA.md`](other其他/FMEA.md) | 风险与改进 / Risks and improvements |
| [`reproduction-guide.md`](other其他/reproduction-guide.md) | 完整复现流程 / Complete reproduction process |
| [`team-profile.md`](other其他/team-profile.md) | 学校、成员、照片和职责 / School, members, portraits and roles |
| [`engineering-log.md`](other其他/engineering-log.md) | 研发阶段和实验计划 / Development stages and experiment plan |
| [`engineering-log.pdf`](other其他/engineering-log.pdf) | 规则要求的结构化可归档双语工程日志 / Structured archival bilingual engineering log required by the rules |
| [`scoring-evidence.md`](other其他/scoring-evidence.md) | 五维评分要求到证据的映射 / Mapping from the five rubric dimensions to evidence |
| [`evidence-register.md`](other其他/evidence-register.md) | 实测、照片和提交缺口登记 / Measurement, photograph and submission gap register |
| [`commit-plan.md`](other其他/commit-plan.md) | 有意义提交的建议拆分 / Recommended grouping for meaningful commits |
| [`competition-checklist.md`](other其他/competition-checklist.md) | 文件、机械、电气和软件检查 / File, mechanical, electrical and software checks |
| [`tests.md`](other其他/tests.md) | 静态、动力、视觉和故障测试 / Static, power, vision and fault tests |
| [`CHANGELOG.md`](other其他/CHANGELOG.md) | 版本迭代 / Version history |

### 照片与视频 / Photographs and Video

- [YouTube自动驾驶演示 / YouTube autonomous-driving demonstration](https://youtu.be/DJcxiJCEFdo) · [视频资料 / Video documentation](video视频/video.md)
- [学校队旗 / School flag](t-photos团队照片/team-flag.jpg) · [正式团队照 / Official team photo](t-photos团队照片/team-official.jpg) · [冠军照 / Award photo](t-photos团队照片/award-beijing-champion.jpg) · [比赛车辆 / Competition vehicle](v-photos车辆照片/vehicle-competition-run.jpg)
- [制作过程照片 / Development-process photographs](t-photos团队照片/README.md) · [车辆照片要求 / Vehicle photograph requirements](v-photos车辆照片/README.md)

## 信息来源 / Sources

- WRO官方Future Engineers模板 / WRO official Future Engineers template：<https://github.com/world-robot-olympiad-association/wro2022-fe-template>
- 团队底盘资料 / Team chassis reference：<https://pjfcckenlt.feishu.cn/wiki/WlCXwfJRCixkGPkZvTIcfUI6nHg>
- 团队提供的2026比赛规则和技术文档评分要求 / 2026 competition rules and technical-document rubric supplied by the team.

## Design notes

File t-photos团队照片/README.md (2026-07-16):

# 团队、赛事成果与制作过程照片 / Team, Competition and Development Photographs

本目录记录南京博颂学校 WRO Future Engineers 队伍的正式团队照、2026 WRO中国区选拔赛（北京站）冠军领奖照，以及控制器装配、接线、编程、讨论和调试阶段的真实制作过程。11张过程照片统一使用 `making-process-XX-内容.jpg` 命名，便于裁判从仓库首页直接查看并追溯研发过程。

This folder contains the official team photograph, the 2026 WRO China Qualification Tournament (Beijing) championship photograph and eleven authentic development-process photographs covering assembly, wiring, programming, discussion and testing.

## 学校队旗 / School Flag

南京博颂学校队旗 / Bona Sonority School Nanjing flag

- 学校 / School：南京博颂学校 / **BONA SONORITY SCHOOL NANJING**
- 完整团队介绍 / Full team profile：[`other其他/team-profile.md`](../other其他/team-profile.md)

## 团队与赛事成果 / Team and Competition Results

| 内容 Content | 文件 File | 状态 Status |
|---|---|---|
| 正式团队照：三名队员与校旗合影 / Official photograph of all three members with the school flag | [`team-official.jpg`](team-official.jpg) | 已完成 / Complete |
| 北京站未来工程师无人驾驶冠军领奖照 / Beijing Future Engineers Autonomous Driving championship photograph | [`award-beijing-champion.jpg`](award-beijing-champion.jpg) | 已完成 / Complete |
| 陆昭颖正式成员照 / Formal portrait of Lu Zhaoying | [`陆昭颖.jpg`](陆昭颖.jpg) | 已完成 / Complete |
| 陆昭颖形象照 / Additional portrait of Lu Zhaoying | [`陆昭颖形象照.jpg`](陆昭颖形象照.jpg) | 已完成 / Complete |
| 张隽泽正式成员照 / Formal portrait of Zhang Junze | [`张隽泽.jpg`](张隽泽.jpg) | 已完成 / Complete |
| 黄鸣博正式成员照 / Formal portrait of Huang Mingbo | [`黄鸣博.jpg`](黄鸣博.jpg) | 已完成 / Complete |
| 全员趣味团队照 / Informal team photograph | `team-funny.jpg` | 待补充 / Pending |

南京博颂学校正式团队照

南京博颂学校北京站冠军领奖照

## 成员照片 / Member Portraits

| 陆昭颖 / Lu Zhaoying | 张隽泽 / Zhang Junze | 黄鸣博 / Huang Mingbo |
|---|---|---|
| 陆昭颖正式成员照 / Formal portrait of Lu Zhaoying | 张隽泽正式成员照 / Formal portrait of Zhang Junze | 黄鸣博正式成员照 / Formal portrait of Huang Mingbo |

### 陆昭颖形象照 / Additional Portrait of Lu Zhaoying

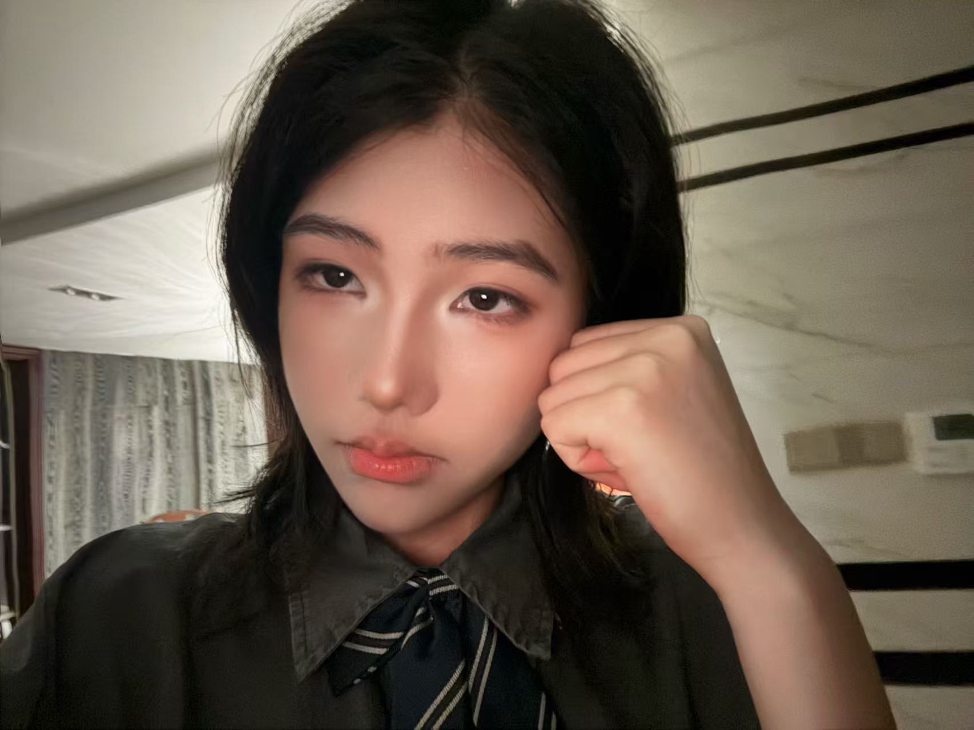
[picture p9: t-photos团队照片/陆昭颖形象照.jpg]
陆昭颖形象照 / Additional portrait of Lu Zhaoying


[陆昭颖自我介绍（中/英/日） / Lu Zhaoying profile (CN/EN/JP)](../other其他/team-profile.md#lu-zhaoying-profile)

## 制作过程照片索引 / Development Process Index

| 编号 No. | 制作环节 Development Activity | 文件 File |
|---:|---|---|
| 01 | 团队研发工作现场 / Team engineering workshop | [`making-process-01-team-workshop.jpg`](making-process-01-team-workshop.jpg) |
| 02 | 软件、硬件与任务讨论 / Software, hardware and task discussion | [`making-process-02-software-discussion.jpg`](making-process-02-software-discussion.jpg) |
| 03 | 控制器连接与硬件调试 / Controller connection and hardware debugging | [`making-process-03-hardware-debug.jpg`](making-process-03-hardware-debug.jpg) |
| 04 | 控制板与连接线装配 / Controller and wiring assembly | [`making-process-04-controller-assembly.jpg`](making-process-04-controller-assembly.jpg) |
| 05 | 底盘和控制模块检查 / Chassis and control-module inspection | [`making-process-05-chassis-check.jpg`](making-process-05-chassis-check.jpg) |
| 06 | 控制器与执行器接线实验 / Controller and actuator wiring | [`making-process-06-controller-wiring.jpg`](making-process-06-controller-wiring.jpg) |
| 07 | 控制板与电子零件调试 / Controller and electronic-component debugging | [`making-process-07-parts-debug.jpg`](making-process-07-parts-debug.jpg) |
| 08 | 程序运行与响应检查 / Program execution and response check | [`making-process-08-program-debug.jpg`](making-process-08-program-debug.jpg) |
| 09 | 程序逻辑与运行结果检查 / Code and result review | [`making-process-09-code-review.jpg`](making-process-09-code-review.jpg) |
| 10 | 根据测试结果修改软件 / Software revision based on tests | [`making-process-10-software-test.jpg`](making-process-10-software-test.jpg) |
| 11 | 控制器功能测试 / Controller functional test | [`making-process-11-controller-test.jpg`](making-process-11-controller-test.jpg) |

## 首页展示图 / Landing-page Image

南京博颂学校团队制作过程

## 规则要求的团队照 / Required Team Photographs

- [x] `team-official.jpg`：全体参赛队员正面、清晰、背景整洁 / all members visible clearly in a formal photograph;
- [ ] `team-funny.jpg`：全体参赛队员入镜的趣味照片 / an informal photograph including all members.

后续趣味团队照应确保所有参赛队员均清晰入镜，同时避免公开不必要的个人隐私。

The future informal team photograph should show every member clearly while avoiding unnecessary disclosure of personal information.

## 团队分工 / Team Roles

| 角色 Role | 主要职责 Main Responsibilities | 姓名 Name |
|---|---|---|
| 程序 / Programming | Orange Pi视觉、算法、GPIO控制、调试与测试日志 / vision, algorithms, GPIO control, tuning and test logs | 陆昭颖 / Lu Zhaoying |
| 结构 / Mechanical Structure | 底盘、摄像头支架、CAD、装配与尺寸复核 / chassis, camera mount, CAD, assembly and dimensional checks | 张隽泽 / Zhang Junze |
| 电子 / Electronics | 供电、Orange Pi GPIO接口、电机驱动、舵机和线束 / power, Orange Pi GPIO interfaces, motor driver, steering servo and wiring | 黄鸣博 / Huang Mingbo |
| 教练 / Coach | 项目指导、安全审查、测试计划与比赛准备 / guidance, safety review, test planning and competition preparation | 薛源 / Xue Yuan |

角色可以协作和重叠，但每名队员都应能解释整车的基本工作原理和本人负责部分。

Roles may overlap through collaboration, but every member should be able to explain the vehicle's basic operation and their own contribution.

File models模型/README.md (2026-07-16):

# 机械模型与尺寸 / Mechanical Models and Dimensions

**当前配置：** 最终装配只需要摄像头视觉支架，不需要超声波支架或编码器信号线。

**Current configuration:** The final assembly requires only a camera mount for vision, with no ultrasonic mounts or encoder signal wiring.

基础机械平台为阿克曼四驱底盘。已确认结构包括前轮舵机转向、四根转向拉杆、四轮驱动、前后差速器、中间传动轴和带霍尔编码器接口的电机。当前只使用电机驱动功能，编码器接口不接线。当前版本由顶部Orange Pi通过GPIO/PWM直接控制舵机和电机驱动器；底板上的UNO安装孔仅是底盘原有孔位，不代表当前安装Arduino。

The mechanical platform is a four-wheel-drive Ackermann chassis. Confirmed features include servo-operated front-wheel steering, four steering links, four-wheel drive, front and rear differentials, a longitudinal driveshaft and motors with Hall-encoder interfaces. Only motor drive is currently used; encoder signals are not connected. In the current version, the upper Orange Pi controls the steering servo and motor driver directly through GPIO/PWM. UNO mounting holes on the lower plate are inherited chassis features and do not indicate that an Arduino is currently installed.

## 团队确认的尺寸与性能 / Team-Confirmed Dimensions and Performance

| 项目 / Item | 数值 / Value |
|---|---:|
| 整车外形 / Overall size | 260 × 140 × 85 mm |
| 去防撞棉主体长度 / Body length without foam bumpers | 246 mm |
| 轴距 / Wheelbase | 174 mm |
| 轮距 / Track width | 123 mm |
| 车轮直径 / Wheel diameter | 47 mm |
| 离地间隙 / Ground clearance | 6 mm |
| 基础重量 / Base mass | 0.7 kg |
| 标称附加载荷 / Rated additional load | 0.3 kg |
| 最小转弯半径 / Minimum turning radius | 475 mm |
| 标称爬坡角 / Rated climbing angle | Below 20° / 小于20° |

安装主控、电池、摄像头和支架后，应重新测量总长、总宽、总高和总质量。

After mounting the controllers, battery, camera and brackets, remeasure overall length, width, height and mass.

本目录中的 `HSP94182层板.dxf` 是可编辑二维CAD文件，可用于层板加工和孔位复核。最终装车后必须逐项核对文件几何与实际层板；当前不宣称它已经是最终比赛版本。

The editable 2D CAD file `HSP94182层板.dxf` supports plate manufacturing and hole-position verification. Its geometry must be checked against the actual plate after final assembly; it is not yet claimed as the final competition version.

## 正式提交前待补 / Items Required Before Final Submission

- 底盘俯视尺寸图：轴距、轮距、轮径、总长、总宽和总高。 / Top-view dimension drawing: wheelbase, track, wheel diameter, overall length, width and height.
- 摄像头支架CAD/STL、距地高度和俯仰角。 / Camera-mount CAD/STL, height above ground and pitch angle.
- 控制板、电池和稳压模块固定件。 / Mounts for controllers, battery and regulators.
- 舵机中位、拉杆孔位和最大安全转角。 / Servo centre, linkage holes and maximum safe steering angle.
- 最终装配图和物料表。 / Final assembly drawing and bill of materials.
- 文件单位、加工方向、材料和紧固件规格。 / File units, manufacturing orientation, materials and fastener specifications.

不要用未经实测的商品页面数据代替最终参赛车辆尺寸。

Do not substitute unmeasured product-page data for final competition-vehicle dimensions.

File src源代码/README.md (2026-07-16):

# 程序说明 / Source Code Guide

> 本文所有内容均为中英直接对照。 / All content is presented in direct Chinese-English pairs.

**现行方案：** `bev_road.py`负责道路/鸟瞰调试，`bev_segmentation.py`负责摄像头、赛道与红绿障碍识别、方向策略和控制循环，`orange_pi_gpio.py`在Orange Pi上直接执行GPIO/PWM输出。当前车辆不安装Arduino，不使用板间串口，不连接超声波，也不读取编码器。

**Current approach:** `bev_road.py` provides road and bird's-eye-view debugging, `bev_segmentation.py` handles the camera, track and red-green obstacle perception, direction strategy and control loop, and `orange_pi_gpio.py` directly executes GPIO/PWM outputs on the Orange Pi. The current vehicle has no Arduino, inter-board serial link, ultrasonic sensors or encoder readings.

## 1. 文件地图 / File Map

| 文件 / File | 平台 / Platform | 功能 / Function | 当前状态 / Current Status |
|---|---|---|---|
| [`bev_road.py`](bev_road.py) | Orange Pi / Python | 亮度、BEV、道路掩膜、连通域和调试图 / Brightness, BEV, road mask, connected components and debug views | 语法通过；透视点待实车标定 / Syntax passed; perspective points require calibration |
| [`bev_segmentation.py`](bev_segmentation.py) | Orange Pi / Python | 红绿识别、方向策略、恢复、仪表板和控制循环 / Red-green detection, direction strategy, recovery, dashboard and control loop | 语法通过；板端与实车待验证 / Syntax passed; board and vehicle tests pending |
| [`orange_pi_gpio.py`](orange_pi_gpio.py) | Orange Pi / Python | GPIO按钮与方向、PWM速度与舵机、状态机和看门狗 / GPIO button and direction, PWM speed and steering, state machine and watchdog | 语法通过；真实映射和波形待验证 / Syntax passed; real mapping and waveforms pending |
| [`gpio_config.example.json`](gpio_config.example.json) | Orange Pi | 默认禁用的GPIO/PWM配置模板 / Disabled-by-default GPIO/PWM configuration template | 所有硬件映射为 `-1`，防止误动作 / All hardware mappings are `-1` to prevent unintended motion |
| [`requirements.txt`](requirements.txt) | Orange Pi | NumPy、OpenCV和python-periphery依赖 / NumPy, OpenCV and python-periphery dependencies | 安装后需冻结实机版本 / Freeze actual installed versions |

## 2. 上一版本与历史实验 / Previous Version and Historical Experiments

下列程序不属于当前装车配置。它们保留用于证明团队迭代过程、底盘方向验证以及控制方案取舍，不得按当前比赛执行链连接或运行。

The following programs are not part of the current vehicle configuration. They are retained to document team iteration, early chassis-direction tests and control trade-offs, and must not be wired or run as the current competition execution chain.

| 文件 / File | 历史用途 / Historical Purpose | 当前边界 / Current Boundary |
|---|---|---|
| [`VisionSerialExecutor.ino`](VisionSerialExecutor/VisionSerialExecutor.ino) | 上一版Arduino串口安全执行 / Previous Arduino serial safety executor | 当前不安装Arduino、不使用串口 / No Arduino or serial link currently |
| [`serial_config.example.json`](serial_config.example.json) | 上一版Orange Pi到Arduino串口配置 / Previous Orange Pi-to-Arduino serial configuration | 历史记录，不被现行程序读取 / Historical record, not read by the current program |
| [`main1.0.ino`](main1.0/main1.0.ino) | 早期双超声波巡墙 / Early dual-ultrasonic wall following | 当前不连接超声波 / Ultrasonic sensors are not connected |
| [`UNO_AT8236`](UNO_AT8236_OpenChallenge/UNO_AT8236_OpenChallenge.ino) | 双PWM、编码器PI与超声波实验 / Dual-PWM, encoder PI and ultrasonic experiment | 历史实验 / Historical experiment |
| [`UNO_DRV8701`](UNO_DRV8701_OpenChallenge/UNO_DRV8701_OpenChallenge.ino) | PWM/DIR、编码器PI与超声波实验 / PWM/DIR, encoder PI and ultrasonic experiment | 历史实验 / Historical experiment |
| [`ESP32_AT8236`](ESP32_AT8236_OpenChallenge/ESP32_AT8236_OpenChallenge.ino) | ESP32电机与编码器实验 / ESP32 motor and encoder experiment | 历史实验；比赛无线关闭 / Historical experiment; radios disabled in competition |

双PWM与PWM/DIR驱动接口不同，不得混用接线或程序。当前 `orange_pi_gpio.py` 按PWM/DIR接口设计；连接前仍需核实实物驱动器接口、有效电平和3.3 V兼容性。

Dual-PWM and PWM/DIR driver interfaces are different and their wiring or code must never be mixed. The current `orange_pi_gpio.py` targets a PWM/DIR interface; verify the physical driver interface, active levels and 3.3 V compatibility before connection.

## 3. 当前软件数据流 / Current Software Data Flow

```mermaid
flowchart LR
  CAM["USB摄像头 / USB camera"] --> V["视觉预处理 / Vision preprocessing"]
  V --> P["道路与红绿识别 / Road and red-green perception"]
  P --> D["方向、转向与速度策略 / Direction, steering and speed strategy"]
  D --> S["GPIO安全状态机 / GPIO safety state machine"]
  B["物理启动/停止按钮 / Physical start-stop button"] --> S
  S --> PWM["电机PWM + 方向GPIO / Motor PWM + direction GPIO"]
  S --> SERVO["舵机PWM / Steering PWM"]
```

视觉控制器给输出层的是逻辑转向量 `-100...100` 与速度量 `-100...100`。输出层完成限幅、方向变化前归零、舵机脉宽换算、物理授权和超时停车。视觉算法不直接散落写GPIO，所有硬件访问集中在 `OrangePiGpioVehicle`。

The vision controller gives the output layer logical steering and speed values in `-100...100`. The output layer performs limits, zero-before-direction-change, steering pulse conversion, physical arming and timeout stopping. GPIO writes are not scattered through vision code; all hardware access is centralised in `OrangePiGpioVehicle`.

## 4. GPIO/PWM配置 / GPIO/PWM Configuration

复制配置模板，但在核验之前保持 `enabled=false`：

Copy the template while keeping `enabled=false` until verification:

```text
gpio_config.example.json -> gpio_config.json
```

需要填写并签字确认的字段如下。仓库故意不提供猜测的引脚号，因为Orange Pi的物理针脚编号、SoC line编号、设备树复用和 `/dev/gpiochipN` line编号不是同一套编号。

The following fields require entry and sign-off. The repository intentionally does not provide guessed pin numbers because Orange Pi physical-header numbers, SoC line numbers, device-tree multiplexing and `/dev/gpiochipN` line numbers are different numbering systems.

| 字段 / Field | 用途 / Purpose | 冻结依据 / Freeze Evidence |
|---|---|---|
| `gpiochip` + `motor_dir_line` | 电机方向GPIO / Motor-direction GPIO | `gpiodetect`、`gpioinfo`、排针对照 / enumeration and header mapping |
| `start_line` | 物理启动/停止输入 / Physical start-stop input | 外部上拉、常开按钮与实测有效电平 / external pull-up, NO button and measured active level |
| `motor_pwm_chip/channel` | 电机速度PWM / Motor-speed PWM | 设备树、`/sys/class/pwm` 与示波器波形 / device tree, sysfs enumeration and oscilloscope waveform |
| `servo_pwm_chip/channel` | 转向舵机PWM / Steering PWM | 设备树、通道占用与舵机脉宽 / device tree, channel ownership and servo pulse width |
| `servo_min/center/max_us` | 舵机安全范围 / Safe steering range | 架空机械极限和预留余量 / lifted-wheel mechanical limits and margin |
| `watchdog_ms` | 控制更新失效停车 / Stale-control stop | G-05实测时间 / measured G-05 timing |

建议枚举命令 / Recommended enumeration commands:

```bash
gpiodetect
gpioinfo
ls -l /dev/gpiochip*
find /sys/class/pwm -maxdepth 3 -type f -o -type l
```

## 5. 安装与运行 / Installation and Running

安装依赖并记录Orange Pi系统镜像、内核、Python、OpenCV、NumPy和python-periphery版本。实际比赛环境应在联网准备阶段完成安装，比赛运行时关闭Wi-Fi和蓝牙。

Install dependencies and record the Orange Pi image, kernel, Python, OpenCV, NumPy and python-periphery versions. Complete installation during connected preparation, then disable Wi-Fi and Bluetooth for competition operation.

```bash
python3 -m pip install -r requirements.txt
python3 bev_road.py
python3 bev_segmentation.py --video-in 0 --mode cw --gpio-config gpio_config.json
```

首次运行必须使用 `enabled=false`。此时状态为 `DRY_RUN`，不打开GPIO/PWM，只显示和记录请求值。完成映射、电气兼容、抬轮与波形检查后，才可将 `enabled` 改为 `true`。

The first run must use `enabled=false`. The state is then `DRY_RUN`: no GPIO/PWM is opened, and requested values are only displayed and logged. Set `enabled` to `true` only after mapping, electrical compatibility, lifted-wheel and waveform checks.

## 6. 安全状态机 / Safety State Machine

| 状态 / State | 进入条件 / Entry | 电机 / Motor | 舵机 / Steering | 退出条件 / Exit |
|---|---|---|---|---|
| `DRY_RUN` | `enabled=false` | 无硬件输出 / No hardware output | 无硬件输出 / No hardware output | 填写配置并人工启用 / Configure and enable manually |
| `WAIT_START` | 硬件打开或人工停车 / Hardware opened or manual stop | 0 | 中位 / Centre | 去抖后的物理按键 / Debounced physical press |
| `GPIO_DRIVE` | 已授权且收到新鲜控制更新 / Armed with fresh control update | 受限PWM / Limited PWM | 受限脉宽 / Limited pulse width | 按键、超时或异常 / Button, timeout or exception |
| `CONTROL_FAILSAFE` | 超过250 ms无新控制更新 / No fresh update for over 250 ms | 0 | 中位 / Centre | 必须重新按键 / Physical re-arm required |
| `CLOSED` | 正常退出或异常清理 / Normal exit or exception cleanup | PWM禁用并清零 / PWM zero and disabled | PWM禁用并释放 / PWM disabled and released | 重新启动程序 / Restart process |

方向变化前先把电机占空比置零，避免在有扭矩时反向。任何配置错误、初始化失败、摄像头丢失、控制异常、键盘中断或程序退出都必须走安全清理路径。

Motor duty is set to zero before direction changes to avoid reversing under torque. Configuration errors, initialisation failures, camera loss, control exceptions, keyboard interrupts and process exit must all use the safe cleanup path.

**重要边界：** 250 ms看门狗是同一Linux进程中的线程，不是独立硬件看门狗。如果Linux内核、PWM子系统或整块Orange Pi冻结，该线程也可能无法停车。必须实测这一残余风险，并决定是否增加独立硬件使能门或电源级失效保护。

**Important boundary:** The 250 ms watchdog is a thread in the same Linux process, not an independent hardware watchdog. If the Linux kernel, PWM subsystem or whole Orange Pi freezes, that thread may also fail to stop the vehicle. Test this residual risk and decide whether an independent hardware enable gate or power-stage fail-safe is required.

## 7. 必做验证 / Required Verification

1. `G-01`：`enabled=false`运行，确认未打开任何GPIO/PWM。 / Run with `enabled=false`; confirm no GPIO/PWM is opened.
2. `G-02`：硬件启用并上电，确认保持 `WAIT_START`、电机0、舵机中位。 / Enable hardware and power up; confirm `WAIT_START`, zero motor and centred steering.
3. `G-03`：按键授权但不发送新控制，确认不运动并进入失效状态。 / Arm without a fresh control update; confirm no motion and fail-safe entry.
4. `G-04`：输入边界与越界值，确认软件限幅和实际波形。 / Apply boundary and out-of-range values; verify limits and waveforms.
5. `G-05`：停止控制更新，测量从最后更新到电机PWM归零的时间。 / Stop control updates and measure time from the last update to zero motor PWM.
6. `G-06`：看门狗后发送新值，确认不自动恢复，必须重新按键。 / Send a new value after timeout; confirm no automatic recovery without re-arming.
7. `G-07`：运动中按键，确认立即停车。 / Press the button while moving; confirm immediate stop.
8. `G-08`：拔摄像头或停止视觉，确认停车。 / Disconnect the camera or stop vision; confirm stopping.
9. `G-09`：异常与进程退出，确认PWM归零/禁用且资源释放。 / Trigger an exception and process exit; confirm PWM zero/disable and resource release.
10. `G-10`：重复上电与正反向切换至少5次，确认方向变化前PWM先归零。 / Repeat power cycles and direction changes at least five times; confirm PWM is zero before direction reversal.

详细表格见 [`../other其他/tests.md`](../other其他/tests.md)，最终接线见 [`../schemes原理图/wiring.md`](../schemes原理图/wiring.md)。

See [`../other其他/tests.md`](../other其他/tests.md) for detailed records and [`../schemes原理图/wiring.md`](../schemes原理图/wiring.md) for final wiring.

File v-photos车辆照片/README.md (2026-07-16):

# 车辆照片拍摄规范 / Vehicle Photograph Specification

## 比赛现场照片 / Competition-Field Photograph

[`vehicle-competition-run.jpg`](vehicle-competition-run.jpg) 展示车辆在WRO场地的外观、摄像头、计算平台和环境。它是赛事证据，不替代结构审查六视图。

[`vehicle-competition-run.jpg`](vehicle-competition-run.jpg) shows the vehicle appearance, camera, compute platform and WRO field environment. It is competition evidence and does not replace structural six-view photographs.

比赛车辆 / Competition vehicle

## 最终六视图（待补） / Final Six Views (Pending)

使用统一背景、光线和距离，只展示最终参赛车辆。 / Use a consistent background, lighting and distance, showing only the final competition vehicle.

| 文件 / File | 方向 / View | 必须可见 / Must Show |
|---|---|---|
| `vehicle-front.jpg` | 前 / Front | 摄像头、前轮、车宽 / Camera, front wheels, width |
| `vehicle-rear.jpg` | 后 / Rear | 驱动和后部线束 / Drive and rear wiring |
| `vehicle-left.jpg` | 左 / Left | 轴距、层板、高度 / Wheelbase, plates, height |
| `vehicle-right.jpg` | 右 / Right | 摄像头安装与侧面结构 / Camera mount and side structure |
| `vehicle-top.jpg` | 顶 / Top | 主控、电源、布局 / Controllers, power, layout |
| `vehicle-bottom.jpg` | 底 / Bottom | 差速器、轴、走线、固定 / Differentials, shaft, wiring, fastening |

可补充拉杆、电机/驱动标签、开关、摄像头尺寸和接线特写。照片必须与代码、CAD和BOM同版本；无需展示未使用的超声波或编码器线。

Additional close-ups may show steering links, motor/driver labels, switches, camera dimensions and wiring. Photographs must match the code, CAD and BOM version; unused ultrasonic or encoder wiring need not be shown.

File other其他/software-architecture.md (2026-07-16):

# 软件架构 / Software Architecture

> 当前版本由Orange Pi同时承担视觉、决策、安全状态和GPIO/PWM执行；Arduino只属于上一版本。 / The current version uses the Orange Pi for vision, decisions, safety state and GPIO/PWM execution; Arduino belongs only to the previous version.

## 1. 现行架构 / Current Architecture

```mermaid
flowchart LR
  C["USB摄像头 / USB camera"] --> A["采集与时间戳 / Capture and timestamp"]
  A --> V["透视、道路、红绿识别 / Perspective, road, red-green perception"]
  V --> D["方向、转向、速度与恢复 / Direction, steering, speed and recovery"]
  D --> B["输出限幅 / Output bounds"]
  B --> S["GPIO安全状态机 / GPIO safety state machine"]
  P["物理按钮 / Physical button"] --> S
  S --> M["电机PWM + DIR GPIO / Motor PWM + DIR GPIO"]
  S --> R["舵机PWM / Steering PWM"]
  W["250 ms进程看门狗 / Process watchdog"] --> S
```

Orange Pi不经过板间串口，直接使用内核GPIO/PWM接口。控制程序只产生逻辑转向和速度目标；`OrangePiGpioVehicle`负责硬件映射、限幅、物理授权、方向切换前归零、看门狗和安全释放。这样可以把所有危险输出集中到一个可审查模块。

The Orange Pi uses kernel GPIO/PWM interfaces directly, without an inter-board serial link. The controller produces only logical steering and speed targets; `OrangePiGpioVehicle` owns hardware mapping, limits, physical arming, zero-before-direction-change, watchdog behaviour and safe release. This centralises all hazardous outputs in one reviewable module.

## 2. 分层与接口 / Layers and Interfaces

| 层级 / Layer | 实现 / Implementation | 输入 / Input | 输出 / Output | 失效处理 / Failure Handling |
|---|---|---|---|---|
| 采集 / Capture | OpenCV/UVC | USB摄像头 / USB camera | 帧 + 单调时间 / Frame + monotonic time | 读取失败立即速度0 / Read failure immediately requests zero speed |
| 感知 / Perception | `bev_road.py`, `bev_segmentation.py` | 图像帧 / Image frame | 道路、边界、红绿障碍 / Road, border and red-green obstacles | 低置信度减速或停车 / Slow or stop on low confidence |
| 决策 / Decision | 方向与恢复状态机 / Direction and recovery state machine | 感知结果 / Perception result | `steer`, `speed` in `-100...100` | 制动动作先置速度0 / Braking actions set speed to zero first |
| 安全输出 / Safety output | `orange_pi_gpio.py` | 逻辑目标 + 按钮 / Logical targets + button | GPIO/PWM / GPIO/PWM | 默认停车、限幅、250 ms失效停车 / Stopped by default, bounded, 250 ms fail-safe |
| 清理 / Cleanup | `stop()` / `close()` | 退出、异常、中断 / Exit, exception, interrupt | PWM 0/禁用，舵机中位 / PWM zero/disabled, steering centred | 幂等执行 / Idempotent execution |

## 3. 配置与硬件抽象 / Configuration and Hardware Abstraction

`gpio_config.json`是本地实机文件并被Git忽略，模板为 `gpio_config.example.json`。模板的 `enabled=false` 且所有映射为 `-1`，因此克隆仓库后不会意外打开执行器。只有完成以下证据后才可启用：

`gpio_config.json` is a local hardware file ignored by Git; `gpio_config.example.json` is the template. The template uses `enabled=false` and `-1` for every mapping, so a fresh clone cannot accidentally activate actuators. Enable it only after collecting the following evidence:

1. 冻结的Orange Pi镜像、内核和设备树版本 / Frozen Orange Pi image, kernel and device-tree version.
2. `/dev/gpiochip*` 与 `/sys/class/pwm` 枚举 / GPIO-chip and PWM enumeration.
3. 物理排针对GPIO line及PWM chip/channel的签字映射 / Signed header-to-line and PWM mapping.
4. 驱动器3.3 V输入兼容性、舵机电源和共地核对 / Driver 3.3 V compatibility, servo supply and common-ground check.
5. 示波器或逻辑分析仪记录的频率、占空比、脉宽和失效停车时间 / Recorded frequency, duty, pulse width and fail-safe timing.

## 4. 安全状态机 / Safety State Machine

```mermaid
stateDiagram-v2
  [*] --> DRY_RUN: enabled=false
  [*] --> WAIT_START: enabled=true and hardware open
  WAIT_START --> GPIO_DRIVE: debounced press + fresh command
  GPIO_DRIVE --> WAIT_START: physical stop press
  GPIO_DRIVE --> CONTROL_FAILSAFE: control age > 250 ms
  CONTROL_FAILSAFE --> WAIT_START: debounced re-arm
  DRY_RUN --> CLOSED: exit
  WAIT_START --> CLOSED: exit or exception
  GPIO_DRIVE --> CLOSED: exit or exception
  CONTROL_FAILSAFE --> CLOSED: exit or exception
```

- `DRY_RUN`不打开GPIO/PWM，仅显示请求值。 / `DRY_RUN` opens no GPIO/PWM and only reports requested values.
- `WAIT_START`保持电机0、舵机中位，旧控制值不能触发运动。 / `WAIT_START` keeps zero motor and centred steering; stale targets cannot cause motion.
- `GPIO_DRIVE`只执行新鲜、有限幅的目标。 / `GPIO_DRIVE` executes only fresh, bounded targets.
- `CONTROL_FAILSAFE`在超过250 ms无更新后停车，并要求重新按键。 / `CONTROL_FAILSAFE` stops after over 250 ms without an update and requires re-arming.
- `CLOSED`禁用PWM并释放资源。 / `CLOSED` disables PWM and releases resources.

## 5. 时间与故障语义 / Timing and Fault Semantics

所有年龄判断使用单调时钟，避免系统时间调整造成误判。视觉读取失败、处理异常、控制循环停滞、物理停止和正常退出都必须把电机置零。方向GPIO改变前先把电机PWM置零，防止带扭矩反向。

All age checks use a monotonic clock so wall-clock changes cannot alter safety timing. Camera-read failure, processing exceptions, a stalled control loop, physical stop and normal exit must all set motor output to zero. Motor PWM is zeroed before changing the direction GPIO to avoid reversing under torque.

**残余风险：** 250 ms看门狗线程与视觉程序位于同一Orange Pi。它可覆盖控制循环停止或异常，但不能保证覆盖Linux内核、PWM子系统、供电或整板冻结。最终风险关闭需要实测故障注入，并决定是否增加独立硬件使能门、常闭急停或驱动器使能的硬件失效保护。

**Residual risk:** The 250 ms watchdog thread shares the Orange Pi with the vision program. It covers a stalled control loop or exception but cannot guarantee coverage of a Linux-kernel, PWM-subsystem, power or complete-board freeze. Closing this risk requires fault-injection testing and a decision on an independent hardware enable gate, normally-closed emergency stop or driver-enable fail-safe.

## 6. 上一版本边界 / Previous-Version Boundary

上一版使用Orange Pi通过文本串口向Arduino发送 `steer,speed`，并由Arduino输出舵机和电机信号。相关 `VisionSerialExecutor.ino`、D2/D6/D7/D8接线和串口配置只作为版本演进证据保留，不属于当前BOM、接线图、运行命令或测试验收。

The previous version sent `steer,speed` text from the Orange Pi to an Arduino, which drove steering and motor signals. Its `VisionSerialExecutor.ino`, D2/D6/D7/D8 wiring and serial configuration remain only as version-history evidence and are not part of the current BOM, wiring, run commands or acceptance tests.

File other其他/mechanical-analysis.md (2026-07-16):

# 机械设计与理论计算 / Mechanical Design and Theoretical Calculations

**当前配置：** 编码器数据仅作底盘规格参考，当前控制不使用编码器反馈。

**Current configuration:** Encoder data is retained only as chassis reference information and is not used for current control.

## 1. 阿克曼转向 / Ackermann Steering

转弯时内前轮半径较小，所以内轮转角应大于外轮。理想关系为：

During a turn, the inner front wheel follows a smaller radius, so its steering angle should be larger. The ideal relationship is:

`cot(δ_outer) - cot(δ_inner) = W / L`

其中 `L` 为轴距，`W` 为轮距。实际关系受舵臂、拉杆孔位、间隙和轮胎变形影响，必须用俯视照片和实测转角验证。

Here `L` is wheelbase and `W` is track width. Servo horn geometry, linkage holes, play and tyre deformation affect the real relationship, which must be verified with top-view photographs and angle measurements.

## 2. 转弯半径 / Turning Radius

等效自行车模型： / Equivalent bicycle model:

`R = L / tan(δ)`

使用 `L=0.174 m` 和标称 `R=0.475 m`： / With `L=0.174 m` and rated `R=0.475 m`:

`δ_equivalent = atan(0.174 / 0.475) ≈ 20.1°`

该角度是转向几何，不是“小于20°”的爬坡指标。最终应低速完整转圈，分别测量左右轨迹半径。

This is a steering-geometry angle, unrelated to the “below 20°” climbing specification. Complete low-speed circles and measure left and right path radii separately.

## 3. 速度参考 / Speed Reference

当前车辆不接编码器，实际速度用固定距离计时。以下公式只解释底盘规格参数：

The current vehicle does not connect encoders; measure actual speed over a fixed distance. The following equation only explains the published chassis data:

`v = ΔN × πD / (CPR × i × Δt)`

使用 `CPR=12`、`i=8.864`、`D=0.047 m`，理论每脉冲约1.39 mm。必须确认CPR计数方式，否则可能产生2倍或4倍误差。

With `CPR=12`, `i=8.864` and `D=0.047 m`, theoretical travel is about 1.39 mm per pulse. The CPR counting convention must be confirmed to avoid twofold or fourfold error.

1692 rpm对应约4.17 m/s，而底盘规格资料另列3.5 m/s参考值。前者视为理论值，后者视为运行参考值，最终以实测为准。

The listed 1692 rpm corresponds to about 4.17 m/s, while the chassis specification also lists a 3.5 m/s reference. Treat the former as theoretical and the latter as practical reference; measurement is authoritative.

## 4. 驱动力与扭矩 / Traction and Torque

- `T_wheel = T_motor × i × η`
- `F_traction = T_wheel / r_wheel`

电机规格为6–12 V、1.9 A、22.8 W；舵机为4.5–7 V、400–800 mA、10 kg·cm。没有扭矩曲线和效率实测时不虚构牵引力，应以斜坡或已知阻力试验验证。

Motor specifications are 6–12 V, 1.9 A and 22.8 W; servo specifications are 4.5–7 V, 400–800 mA and 10 kg·cm. Do not invent traction without torque-curve and efficiency measurements; validate it with a ramp or known-resistance test.

## 5. 重心与安装 / Centre of Gravity and Mounting

- 电池和重件低位居中 / Keep the battery and heavy parts low and central.
- 线束远离拉杆、轴和轮胎 / Keep wiring away from links, shafts and tyres.
- 摄像头支架必须刚性且可重复定位 / Make the camera bracket rigid and repeatable.
- 电路板使用绝缘垫柱 / Use insulating standoffs under circuit boards.
- 可调结构做位置标记 / Mark all adjustable structures.

## 6. 机械验收 / Mechanical Acceptance

| 项目 / Item | 方法 / Method | 合格判据 / Criterion |
|---|---|---|
| 转向中位 / Steering centre | 低速直行2 m / 2 m low-speed straight run | 无持续偏转 / No persistent drift |
| 左右极限 / Limits | 抬轮逐度测试 / Lifted-wheel angle steps | 无顶死或干涉 / No stall or interference |
| 回差 / Backlash | 双向回中测角 / Approach centre from both sides | 可重复并记录 / Repeatable and recorded |
| 轮胎车轴 / Wheels and axles | 手动转动 / Rotate manually | 无卡滞松旷 / No binding or looseness |
| 紧固件 / Fasteners | 扭矩与标记 / Torque and marks | 无松动缺件 / No loose or missing parts |
| 摄像头支架 / Camera mount | 轻触后复查ROI / Recheck ROI after light touch | 画面稳定 / Image remains stable |
| 线束 / Wiring | 全转向观察 / Observe full steering travel | 无拉扯夹擦 / No pull, pinch or rub |

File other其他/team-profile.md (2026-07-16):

# 团队介绍 / Team Profile

## 学校与队伍 / School and Team

**中文：** 我们来自南京博颂学校，参加 WRO Future Engineers（未来工程师）项目。团队以阿克曼无人驾驶车辆为工程平台，当前使用USB彩色摄像头和Orange Pi完成视觉感知、决策以及GPIO/PWM转向和电机控制。Arduino属于上一版本，当前车辆不安装。

**English:** We are the Future Engineers team from **BONA SONORITY SCHOOL NANJING**. Our engineering platform is an autonomous Ackermann-steering vehicle. The current vehicle uses a USB colour camera and an Orange Pi for vision, decision-making and direct GPIO/PWM steering and motor control. Arduino belongs to the previous version and is not installed on the current vehicle.

- 学校中文名 / Chinese school name：**南京博颂学校**
- 学校英文名 / English school name：**BONA SONORITY SCHOOL NANJING**
- 参赛组别 / Category：**WRO Future Engineers / 未来工程师**
- 当前感知方案 / Current perception：**USB摄像头视觉 / USB camera vision only**

## 学校队旗 / School Flag

南京博颂学校队旗 / Bona Sonority School Nanjing flag

**中文：** 队旗使用深蓝色背景、白色学校标志，并同时展示“南京博颂学校”和“BONA SONORITY SCHOOL NANJING”。比赛现场合影中的队旗与本文件一致。

**English:** The team flag uses a dark-blue background and the white school emblem, together with the names “南京博颂学校” and “BONA SONORITY SCHOOL NANJING”. The same flag appears in the team's competition photographs.

## 团队成员 / Team Members

| 姓名 Name | 分工 Role | 主要职责 Main Responsibilities |
|---|---|---|
| 陆昭颖 / Lu Zhaoying | 程序 / Programming | Orange Pi视觉程序、道路与红绿障碍识别、GPIO控制、参数调试、软件测试与日志 / Orange Pi vision, road and red/green obstacle detection, GPIO control, parameter tuning, software tests and logs |
| 张隽泽 / Zhang Junze | 结构 / Mechanical Structure | 阿克曼底盘、层板与摄像头支架、机械装配、尺寸复核、转向限位与CAD资料 / Ackermann chassis, plates and camera mount, mechanical assembly, dimensional checks, steering limits and CAD records |
| 黄鸣博 / Huang Mingbo | 电子 / Electronics | 电源与配电、Orange Pi GPIO接口、电机驱动、舵机与线束、共地和上电安全检查 / Power distribution, Orange Pi GPIO interfaces, motor driver, steering servo and wiring, common ground and power-on safety checks |
| 薛源 / Xue Yuan | 教练 / Coach | 项目指导、安全审查、测试计划、技术文档和比赛准备 / Project guidance, safety review, test planning, technical documentation and competition preparation |

## 成员照片 / Member Portraits

| 成员 Member | 照片 Portrait | 介绍 Profile |
|---|---|---|
| **陆昭颖 / Lu Zhaoying** | 陆昭颖正式照片 / Formal portrait of Lu Zhaoying | **程序 / Programming**：负责Orange Pi视觉程序、道路与障碍识别、GPIO控制、参数调试和软件测试。 / Responsible for Orange Pi vision, road and obstacle detection, GPIO control, parameter tuning and software testing. |
| **张隽泽 / Zhang Junze** | 张隽泽正式照片 / Formal portrait of Zhang Junze | **结构 / Mechanical Structure**：负责阿克曼底盘、摄像头支架、机械装配、尺寸复核和转向限位。 / Responsible for the Ackermann chassis, camera mount, mechanical assembly, dimensional verification and steering limits. |
| **黄鸣博 / Huang Mingbo** | 黄鸣博正式照片 / Formal portrait of Huang Mingbo | **电子 / Electronics**：负责供电、Orange Pi GPIO接口、电机驱动、舵机、线束和上电安全。 / Responsible for power, Orange Pi GPIO interfaces, motor driver, steering servo, wiring and power-on safety. |

### 陆昭颖形象照 / Additional Portrait of Lu Zhaoying

陆昭颖形象照 / Additional portrait of Lu Zhaoying

**中文：** 此照片作为成员形象补充展示；正式成员识别与资料索引优先使用上方白底证件照。

**English:** This photograph is included as an additional team-member portrait. The formal white-background portrait above remains the primary identification image in the documentation.

## 陆昭颖自我介绍 / Lu Zhaoying Self-Introduction / 夏樹エイの自己紹介

### 中文 / Chinese / 中国語

大家好，我是陆昭颖（Aorta），来自南京博颂学校，是一名15岁的高一学生。在本队中，我主要负责程序开发，包括Orange Pi视觉程序、赛道与红绿障碍识别、GPIO控制、参数调试、软件测试和研发日志记录。

我的兴趣和很多人一样，既包括乐器，也包括运动。我喜欢古筝和羽毛球，也喜欢玩游戏。我常玩的音乐游戏有《Phigros》《Paradigm: Reboot》《Rizline》《Lanota》和《Milthm》，此外也喜欢《和平精英》和《极品飞车》。如果你也玩《和平精英》，欢迎加我为游戏好友。

我的MBTI是ISTJ。初次见面时我可能比较内向，甚至不太说话，这对我来说是正常的。目前我重点学习数学、物理、化学和生物，也欢迎有经验的同学与我交流学习方法和经验。

很高兴认识大家。如果有机会交流，还请多多关照。

### English / 英文 / 英語

Hello! My name is Lu Zhaoying (Aorta), and I am a 15-year-old Grade 10 student at Bona Sonority School Nanjing. In our team, I am mainly responsible for programming, including Orange Pi vision software, track and red/green obstacle detection, GPIO control, parameter tuning, software testing and engineering-log maintenance.

Like many people, I enjoy both musical instruments and sports. I play the guzheng, a traditional Chinese zither, and badminton. I also enjoy video games. The music games I often play include *Phigros*, *Paradigm: Reboot*, *Rizline*, *Lanota* and *Milthm*. I also like *Game for Peace* and *Need for Speed*. If you play *Game for Peace* too, feel free to add me as an in-game friend.

My MBTI type is ISTJ. I may be rather quiet—or even not speak much—when meeting someone for the first time, which is completely normal for me. I currently focus on mathematics, physics, chemistry and biology, and I would be happy to exchange study methods and learning experiences with other students.

It is a pleasure to meet you, and I look forward to getting to know you.

### 日本語 / Japanese / 日文

皆さん、こんにちは。南京博頌学校高等部1年の夏樹エイ（Lu Zhaoying / Aorta）です。15歳です。チームでは主にプログラミングを担当し、Orange Piの画像認識プログラム、コースと赤・緑の障害物の認識、GPIO制御、パラメータ調整、ソフトウェアテスト、開発記録の作成に取り組んでいます。

趣味は楽器とスポーツです。古筝（中国の伝統的な弦楽器）とバドミントンが好きです。また、ゲームも好きで、*Phigros*、*Paradigm: Reboot*、*Rizline*、*Lanota*、*Milthm*などの音楽ゲームのほか、*Game for Peace*や*Need for Speed*も遊んでいます。*Game for Peace*を遊んでいる方は、よければゲーム内でフレンドになってください。

MBTIはISTJです。初対面では少し人見知りで、あまり話さないこともありますが、私にとっては自然なことです。学校では数学、物理、化学、生物を重点的に学んでいます。勉強方法や学習経験について、皆さんと交流できればうれしいです。

お話しする機会がありましたら、どうぞよろしくお願いします。

## 协作方式 / Collaboration

**中文：** 程序、结构和电子三部分通过统一接口协作。结构组保证摄像头和Orange Pi安装可重复；电子组保证供电、GPIO/PWM、执行器和线束可靠；程序组根据固定的摄像头位置完成视觉标定并输出受限转向/速度。每次更改机械位置、GPIO映射、接线或软件参数后，团队都应重新完成抬轮检查、低速测试和故障停车测试。

**English:** Programming, mechanical structure and electronics are connected through defined interfaces. The mechanical role keeps the camera and Orange Pi repeatably mounted; the electronics role provides reliable power, GPIO/PWM, actuators and wiring; the programming role calibrates vision for the fixed camera position and produces limited steering/speed output. After any mechanical, GPIO mapping, wiring or software change, the team repeats the lifted-wheel check, low-speed test and failure-stop test.

## 相关资料 / Related Materials

- [正式团队照 / Official team photograph](../t-photos团队照片/team-official.jpg)
- [北京站冠军领奖照 / Beijing championship award photograph](../t-photos团队照片/award-beijing-champion.jpg)
- [制作过程照片 / Development process photographs](../t-photos团队照片/README.md)
- [车辆比赛现场 / Vehicle on the competition field](../v-photos车辆照片/vehicle-competition-run.jpg)
- [工程研发日志 / Engineering log](engineering-log.md)

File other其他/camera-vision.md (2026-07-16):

# USB摄像头规格、安装与视觉方案 / USB Camera Specifications, Mounting and Vision

## 1. 实际购买版本 / Purchased Version

商品链接 / Product link：<https://item.taobao.com/item.htm?id=632892015154>

商品包含多种视场、帧率、彩色/黑白和夜视组合。订单截图对应以下SKU。

The product includes multiple fields of view, frame rates, colour/monochrome and night-vision combinations. The order screenshot identifies the following SKU.

| 参数 / Parameter | 团队版本 / Team Version | 证据状态 / Evidence Status |
|---|---|---|
| 接口 / Interface | USB有线 / Wired USB | 商品确认 / Product confirmed |
| 驱动 / Driver | UVC免驱 / Driver-free UVC | 页面确认，Linux待验 / Page confirmed; Linux pending |
| 图像 / Image | 彩色 / Colour | SKU确认 / SKU confirmed |
| 帧率 / Frame rate | 30 FPS | SKU确认 / SKU confirmed |
| 清晰度 / Resolution | 480p | SKU确认 / SKU confirmed |
| 视场 / Field of view | 160°广角 / 160° wide angle | SKU确认 / SKU confirmed |
| 镜头 / Lens | 有畸变 / Distorted | SKU明确 / Explicit SKU |
| 夜视 / Night vision | 非夜视 / None | SKU确认 / SKU confirmed |
| 传感器 / Sensor | GC0308 | 商品标题 / Product title |
| 品牌型号 / Brand and recorded model | HBVCAM / HBVCAM-1914S V44 | 团队购买记录 / Team purchase record |
| 类型 / Type | CMOS, 30万像素 / CMOS, 0.3 MP | 团队购买记录 / Team purchase record |
| 页面系统 / Listed systems | Windows, Android, macOS等 / etc. | Linux待验 / Linux pending |

商品页的“最大1920×1080”与30万像素、480p SKU冲突，可能是多SKU共用字段。本项目以480p/30 FPS为标称模式，并以Orange Pi实际UVC枚举为最终依据。

The page's “maximum 1920×1080” conflicts with 0.3 MP and the 480p SKU and may be a shared multi-SKU field. This project uses 480p/30 FPS as the nominal mode and treats actual Orange Pi UVC enumeration as authoritative.

## 2. 车载处理 / Onboard Processing

摄像头连接 **Orange Pi Zero 3W 4GB**。A733 CPU在Linux/OpenCV中完成采集、去畸变、HSV分割和轮廓筛选。当前算法不依赖NPU，只有完成模型转换、延迟和精度验证后才能声称使用3 TOPS NPU。

The camera connects to an **Orange Pi Zero 3W 4GB**. Its A733 CPU runs capture, undistortion, HSV segmentation and contour filtering under Linux/OpenCV. The current algorithm does not depend on the NPU; use of the 3 TOPS NPU may only be claimed after model conversion, latency and accuracy validation.

摄像头通过USB接入Orange Pi。视觉结果在同一进程内转换为受限转向和速度目标，再由Orange Pi GPIO/PWM直接驱动舵机和电机驱动器；当前没有Arduino串口链路，也没有独立距离传感器。

The camera connects to the Orange Pi through USB. Vision results are converted in the same process into limited steering and speed targets, then applied directly to the steering servo and motor driver through Orange Pi GPIO/PWM. The current version has no Arduino serial link and no independent range sensor.

仓库中的 `bev_road.py` 用于道路掩膜、实验性BEV和连通域，`bev_segmentation.py` 包含红绿HSV、CW/CCW策略、道路密度转向和恢复状态机，`orange_pi_gpio.py` 提供默认禁用、物理启动、GPIO/PWM限幅和250 ms进程级看门狗。目前已完成语法检查，实物GPIO映射和车辆测试仍待完成。

In the repository, `bev_road.py` provides road masks, experimental BEV and connected components; `bev_segmentation.py` contains red-green HSV detection, CW/CCW strategy, road-density steering and recovery states; and `orange_pi_gpio.py` provides disabled-by-default output, physical arming, GPIO/PWM limits and a 250 ms process-level watchdog. Syntax checks are complete, while physical GPIO mapping and vehicle tests remain pending.

## 3. 选择30 FPS彩色的原因 / Why 30 FPS Colour Was Selected

WRO障碍任务需要区分红色和绿色。商品的120 FPS版本为黑白，不能直接保留颜色信息，因此选择30 FPS彩色版本。

The WRO obstacle task requires red-green classification. The product's 120 FPS version is monochrome and cannot directly preserve colour, so the 30 FPS colour version was selected.

车辆以0.35 m/s行驶时，每帧理论位移为： / At 0.35 m/s, theoretical travel per frame is:

`0.35 / 30 ≈ 0.0117 m = 11.7 mm`

实际延迟还包括USB、曝光和处理，应测量端到端延迟并始终处理最新帧。

Actual latency also includes USB transfer, exposure and processing. Measure end-to-end latency and always process the newest frame.

## 4. 160°广角取舍 / 160° Wide-Angle Trade-off

优点是覆盖前方和两侧、近距离障碍不易离开画面、便于观察弯角。代价是桶形畸变、单位目标像素更少和边缘误差更大。必须使用标定、去畸变或查表补偿，并测量不同位置和距离的检测误差。

Advantages are broad front/side coverage, retention of nearby obstacles in view and improved corner visibility. Costs are barrel distortion, fewer pixels per target and larger edge errors. Calibration, undistortion or lookup compensation is required, together with error measurements at different positions and distances.

## 5. 安装 / Mounting

- 安装在车辆纵向中心附近并朝向正前方 / Mount near the longitudinal centre and point straight ahead.
- 支架可重复定位并标记角度 / Use a repeatable bracket with angle marks.
- 同时看到障碍主体和接地区域，减少车身遮挡 / View obstacle bodies and ground contact while reducing body occlusion.
- 防止线束、支架或层板遮挡镜头 / Prevent wiring, bracket or plate obstruction.
- 固定USB插头，避免振动瞬断 / Mechanically secure the USB plug against vibration.
- 避免强灯直射，必要时加遮光罩 / Avoid direct strong light and add a hood if needed.
- 固定焦距后标定，角度变化后重新验证 / Calibrate after focus is fixed and revalidate after angle changes.

最终必须记录距地高度、相对前轴距离、俯仰角和安装照片；当前没有实测数据，不填写假值。

Final records must include height above ground, distance from the front axle, pitch angle and mounting photographs. No values are invented before measurement.

## 6. 障碍识别流程 / Obstacle-Detection Pipeline

1. 获取最新480p彩色帧 / Acquire the latest 480p colour frame.
2. 使用标定参数去畸变 / Undistort with calibration parameters.
3. 裁剪可行驶区域ROI / Crop the drivable-region ROI.
4. 转为HSV或Lab / Convert to HSV or Lab.
5. 生成红绿掩膜；红色使用两段色相 / Build red and green masks; use two hue ranges for red.
6. 开运算去噪、闭运算填补 / Apply opening for noise and closing for gaps.
7. 按面积、比例、位置和连续帧筛选 / Filter by area, aspect, location and temporal stability.
8. 输出 `{color, center_x, bottom_y, area, confidence, timestamp}` / Output the same record.
9. 状态机规划通过侧；超时或低置信度时停车 / Plan the passing side; stop on timeout or low confidence.

## 7. 性能指标 / Performance Metrics

| 指标 / Metric | 方法 / Method | 当前值 / Current Value | 用途 / Purpose |
|---|---|---|---|
| 分辨率与FPS / Resolution and FPS | 枚举+1000帧计时 / Enumeration + 1000-frame timing | 待测 / TBD | 确认UVC模式 / Confirm UVC mode |
| 端到端延迟 / End-to-end latency | 时间戳或高速录像 / Timestamps or high-speed video | 待测 / TBD | 安全距离 / Safety distance |
| 红/绿召回率 / Red/green recall | 多位置和光照标注集 / Labelled positions and lighting | 待测 / TBD | 减少漏检 / Reduce misses |
| 颜色误判率 / Colour error rate | 红绿混合数据 / Mixed red-green data | 待测 / TBD | 防止方向错误 / Prevent wrong avoidance |
| 空场误检 / Empty-track false positives | 无障碍完整回合 / Obstacle-free laps | 待测 / TBD | 防止无故转向 / Avoid false steering |
| 稳定检测距离 / Stable detection range | 逐级增加距离 / Incremental distance | 待测 / TBD | 设置减速点 / Set slowdown point |
| 边缘误差 / Edge-position error | 多横向角度标定 / Multiple lateral angles | 待测 / TBD | 验证去畸变 / Validate undistortion |
| 30分钟稳定性 / 30-minute stability | 掉帧、负载、温度 / Drops, load and temperature | 待测 / TBD | 验证USB和散热 / Validate USB and cooling |
| GPIO控制延迟 / GPIO control latency | 采集到PWM/GPIO变化 / Capture to PWM/GPIO change | 待测 / TBD | 计算停车距离 / Calculate stopping distance |

## 8. 车载核验 / Onboard Verification

在Orange Pi使用 `lsusb`、`v4l2-ctl --list-devices` 和 `v4l2-ctl --list-formats-ext -d /dev/video0` 检查设备、格式、分辨率和帧率。程序必须打印实际width/height/fps。拔掉摄像头、遮挡镜头和重启视觉进程均应产生可预测停车。

On the Orange Pi, use `lsusb`, `v4l2-ctl --list-devices` and `v4l2-ctl --list-formats-ext -d /dev/video0` to inspect devices, formats, resolutions and frame rates. The program must print actual width/height/fps. Camera removal, lens obstruction and vision-process restart must all cause a predictable stop.

## 9. 规则与安全 / Rules and Safety

摄像头是唯一环境感知设备，所有处理和GPIO/PWM控制均在Orange Pi上完成。比赛期间不使用Wi-Fi或蓝牙传输图像或控制。摄像头或视觉进程失效时，程序必须立即把电机PWM置零；进程级看门狗处理控制更新停滞。没有Arduino或超声波安全层。

The camera is the only environmental sensor, and all processing plus GPIO/PWM control occurs on the Orange Pi. Wi-Fi and Bluetooth are not used for images or control during competition. Camera or vision-process failure must immediately set motor PWM to zero, while a process-level watchdog handles missing control updates. No Arduino or ultrasonic safety layer exists.

## 10. 信息来源 / Sources

参数整理于2026-07-14，来源为团队订单记录和SKU截图。网页信息可能变化，且记录中存在分辨率表述冲突；最终结论必须以实物照片和车载UVC枚举结果为准。

Parameters were compiled on 2026-07-14 from the team order record and SKU screenshot. Online information may change and the record contains conflicting resolution claims; final conclusions must therefore be based on hardware photographs and onboard UVC enumeration.

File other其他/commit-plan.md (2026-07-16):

# 建议提交计划 / Recommended Commit Plan

规则要求主分支至少有3条说明明确的有效提交。以下只是提交拆分建议；本次文档更新不会自动提交、暂存或推送，由队伍检查后自行执行。

The rubric requires at least three clearly described meaningful commits on the main branch. The following is only a grouping recommendation. This documentation update does not automatically commit, stage or push; the team should review and perform those actions.

| 顺序 / Order | 建议提交说明 / Suggested Commit Message | 应包含 / Include | 验收 / Acceptance |
|---:|---|---|---|
| 1 | `docs: map 2026 rubric evidence and add archival engineering log` | 评分地图、证据登记、README、工程日志PDF / Rubric map, evidence register, README and engineering-log PDF | 链接可用，PDF可读 / Links valid; PDF readable |
| 2 | `control: switch current vehicle to Orange Pi direct GPIO output` | `orange_pi_gpio.py`、GPIO配置、源代码说明、软件架构、测试 / GPIO output, configuration, code guide, architecture and tests | Python检查通过；实物映射和架空故障测试完成 / Python checks pass; physical mapping and lifted fault tests complete |
| 3 | `hardware: add vision-only wiring diagram and verified pin map` | PNG/SVG接线图、接线说明、实物照片 / PNG/SVG diagram, wiring guide and hardware photos | 型号/电压/引脚与实车一致 / Models, voltages and pins match vehicle |
| 4 | `test: record power vision and full-lap validation results` | 真实测试表、日志、照片、参数 / Actual tests, logs, photographs and parameters | 原始证据与汇总一致 / Raw evidence matches summary |
| 5 | `release: freeze competition configuration and video mapping` | 版本号、提交SHA、镜像校验值、视频元数据、检查表 / Version, SHA, image checksum, video metadata and checklist | 截止前公共仓库可访问 / Public repository accessible before deadline |

不要为了“提交次数”制造空提交，也不要把上述工程主题压缩为一个含糊的“更新”。每次提交说明应指出子系统和工程目的；测试失败也应保留，并在下一次提交说明修复依据。

Do not create empty commits merely to increase the count, and do not squash these engineering themes into a vague “update”. Each message should name the subsystem and engineering purpose. Preserve failed tests and explain the evidence behind the next fix.

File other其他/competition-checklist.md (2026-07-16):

# 比赛前检查表 / Competition Checklist

本检查表用于视觉唯一感知车辆，不包含超声波或编码器检查。 / This checklist is for the vision-only vehicle and contains no ultrasonic or encoder checks.

## 文件提交 / Repository Submission

- [ ] 仓库公开可访问 / Repository is publicly accessible.
- [ ] 提交记录和说明反映研发 / Commit history and messages reflect development.
- [ ] README满足当年要求 / README meets current-year requirements.
- [x] 五维评分证据地图和缺失证据登记表已建立 / Five-dimension evidence map and missing-evidence register created.
- [x] 双语结构化工程日志PDF已归档 / Bilingual structured engineering-log PDF archived.
- [x] 正式团队照、冠军照和比赛车辆照已归档 / Official team, award and competition-vehicle photos archived.
- [ ] 趣味团队照、黄鸣博个人照和车辆六视图已补 / Informal team photo, Huang Mingbo portrait and six views added.
- [ ] CAD、接线、BOM、代码和测试与实车一致 / CAD, wiring, BOM, code and tests match the vehicle.
- [ ] PNG接线图中的型号、额定值和引脚均由实物核验 / Models, ratings and pins in the PNG wiring diagram are physically verified.
- [ ] 演示视频公开可访问且版本已记录 / Video is accessible and its version recorded.
- [ ] 截止前提交并保存提交号/截图 / Submit before deadline and save commit/screenshots.

## 机械 / Mechanical

- [ ] 轮胎、拉杆、舵臂、螺母、传动轴和差速器正常 / Tyres, links, horn, nuts, shaft and differentials are sound.
- [ ] 电池、层板和摄像头支架牢固 / Battery, plates and camera mount are secure.
- [ ] 摄像头高度与角度正确 / Camera height and angle are correct.
- [ ] 线束远离车轮和传动件 / Wiring is clear of wheels and drivetrain.
- [ ] 车辆尺寸合规 / Vehicle dimensions comply.

## 电气 / Electrical

- [ ] 电池电压、极性、共地、保险和总开关正常 / Battery voltage, polarity, ground, fuse and main switch are correct.
- [ ] 舵机和电机不从Orange Pi排针取大电流 / Servo and motor do not draw load current from the Orange Pi header.
- [ ] Orange Pi 5 V、USB-C、摄像头、GPIO/PWM和共地连接牢固 / Orange Pi 5 V, USB-C, camera, GPIO/PWM and common-ground connections are secure.
- [ ] 启动按钮有效，上电保持停止 / Start button works and vehicle stays stopped at power-up.
- [ ] Wi-Fi、蓝牙和热点关闭，`rfkill`/`ip link`通过 / Wi-Fi, Bluetooth and hotspot disabled; checks pass.
- [ ] 无异常热、味或舵机嗡鸣 / No abnormal heat, smell or servo buzz.

## 软件与场地 / Software and Field

- [x] `orange_pi_gpio.py` 与视觉程序通过Python语法检查 / `orange_pi_gpio.py` and the vision program pass Python syntax checks.
- [ ] 冻结并记录实际GPIO line、PWM chip/channel、设备树和权限 / Freeze and record actual GPIO lines, PWM chip/channels, device tree and permissions.
- [ ] G-01至G-10 GPIO安全测试均有结果和证据 / Record results and evidence for GPIO safety tests G-01 through G-10.
- [ ] 冻结镜像离线自动启动 / Frozen image autostarts offline.
- [ ] 识别4 GB、摄像头、gpiochip和PWM设备 / 4 GB, camera, gpiochip and PWM devices are recognised.
- [ ] 保存提交、编译和参数 / Commit, build and parameters saved.
- [ ] 舵机、电机和视觉命令方向正确 / Servo, motor and vision-command directions correct.
- [ ] 文档与无超声波/编码器实车一致 / Documentation matches no-sensor wiring.
- [ ] 摄像头失效、视觉异常、控制更新停滞和程序退出均停车 / Camera failure, vision exception, stale control update and program exit all stop the vehicle.
- [ ] 30分钟温度、FPS和5 V正常 / Temperature, FPS and 5 V remain normal for 30 minutes.
- [ ] ROI、曝光、白平衡和红绿阈值适应现场 / ROI, exposure, white balance and thresholds suit field.
- [ ] 至少完成一个完整回合 / At least one full lap completed.
- [ ] 提交满分证据前完成连续10回合、识别率、延迟、功耗和故障注入表 / Before a full-score claim, complete ten consecutive laps, recognition, latency, power and fault-injection records.

## 上场记录 / Run Record

- 回合 / Run:
- 提交 / Commit:
- 电池与电压 / Battery and voltage:
- 参数 / Parameters:
- 成绩与时间 / Score and time:
- 触碰或失误 / Contacts or errors:
- 日志/视频 / Log/video:
- 下一轮唯一修改 / Only change for next run:

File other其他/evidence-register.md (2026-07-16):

# 实测与照片证据登记表 / Measurement and Photograph Evidence Register

本表用于把“待补”变成可执行任务。文件名、方法和验收标准已经预先定义；完成后在结果栏写入真实值并链接原始照片、日志或视频。不得补写不存在的测试。

This register converts “pending” items into executable tasks. Filenames, methods and acceptance criteria are predefined; after completion, enter the actual result and link the original photograph, log or video. Never backfill a test that did not occur.

## A. 机械与车辆照片 / Mechanical and Vehicle Photographs

| ID | 证据 / Evidence | 建议文件名 / Suggested Filename | 方法与画面要求 / Method and Framing | 状态/结果 / Status or Result |
|---|---|---|---|---|
| M-01 | 车辆前视 / Vehicle front | `v-photos车辆照片/vehicle-front.jpg` | 白/灰背景，车体居中，完整边界，无透视裁切 / Neutral background, centred, complete outline | 待拍 / Pending |
| M-02 | 车辆后视 / Vehicle rear | `vehicle-rear.jpg` | 同M-01 / Same as M-01 | 待拍 / Pending |
| M-03 | 车辆左视 / Vehicle left | `vehicle-left.jpg` | 镜头与车体中高处平行 / Camera parallel at mid-height | 待拍 / Pending |
| M-04 | 车辆右视 / Vehicle right | `vehicle-right.jpg` | 与左视相同焦距和距离 / Same focal length and distance as left | 待拍 / Pending |
| M-05 | 车辆俯视 / Vehicle top | `vehicle-top.jpg` | 相机垂直，清晰显示设备布局与线束 / Camera perpendicular; layout and wiring visible | 待拍 / Pending |
| M-06 | 车辆底视 / Vehicle bottom | `vehicle-bottom.jpg` | 安全支撑车辆，显示传动、转向和底盘 / Safely support vehicle; show drivetrain and steering | 待拍 / Pending |
| M-07 | 尺寸测量 / Dimensions | `measurement-dimensions.jpg` | 同一画面或组图显示长宽高和量具 / Show L/W/H and measuring tool | 待测 / Pending |
| M-08 | 整车质量 / Assembled mass | `measurement-mass.jpg` | 电子秤归零，显示整车与读数 / Tared scale, full vehicle and reading | 待测 / Pending |
| M-09 | 转向极限 / Steering limits | `steering-limits.jpg` | 左/中/右俯视组图，标角度 / Left/centre/right top views with angles | 待测 / Pending |
| M-10 | 转弯半径 / Turning radius | `turning-radius-test.jpg` | 标出轨迹圆、起点和卷尺 / Mark path circle, start and tape | 待测 / Pending |
| M-11 | 摄像头支架图 / Camera mount drawing | `camera-mount.*` | CAD + 关键尺寸 + 材料 + 固定方式 / CAD, dimensions, material and mounting | 待设计归档 / Pending |

## B. 团队证据 / Team Evidence

| ID | 证据 / Evidence | 文件名 / Filename | 状态 / Status |
|---|---|---|---|
| T-01 | 全员正式团队照 / Official all-member photo | `team-official.jpg` | 已有 / Present |
| T-02 | 全员趣味团队照 / Informal all-member photo | `team-funny.jpg` | 待拍 / Pending |
| T-03 | 黄鸣博正式照片 / Huang Mingbo portrait | `t-photos团队照片/黄鸣博.jpg` | 已有 / Present |
| T-04 | 制作过程原始照片 / Development process originals | `making-process-01...11` | 已有 / Present |

## C. 电气与动力 / Electrical and Power

| ID | 项目 / Item | 记录内容 / Required Record | 方法 / Method | 状态/结果 / Status or Result |
|---|---|---|---|---|
| E-01 | 电池 / Battery | 型号、电压、容量、最大放电、插头、照片 / Model, V, capacity, max discharge, connector, photo | 读取实物标签，不凭记忆 / Read physical label | 待核 / Pending |
| E-02 | 电机驱动器 / Motor driver | 型号、接口、逻辑电平、连续/峰值电流、照片 / Model, interface, logic, current, photo | 对照板上丝印和说明书 / Board markings and datasheet | 待核 / Pending |
| E-03 | 舵机 / Servo | 型号、电压、堵转电流、扭矩、死区 / Model, voltage, stall current, torque, deadband | 标签+电流测试 / Label + current test | 待核 / Pending |
| E-04 | Orange Pi稳压 / Regulator | 型号、输入、5 V输出、连续/峰值、效率 / Model, input, 5 V output, current, efficiency | 标签+负载测试 / Label + load test | 待核 / Pending |
| E-05 | 保护 / Protection | 总开关、保险规格、线径 / Main switch, fuse and wire gauge | 根据实测峰值和线材额定值选择 / Select from measured peak and wire rating | 待核 / Pending |
| E-06 | 静止功耗 / Idle power | 电池U/I、Orange Pi 5 V / Battery V/I, Orange Pi 5 V | 稳态30 s，记录均值/最小 / 30 s mean/min | 待测 / Pending |
| E-07 | 视觉功耗 / Vision power | 摄像头+视觉运行U/I / Camera + vision V/I | 稳态60 s / 60 s steady | 待测 / Pending |
| E-08 | 电机启动 / Motor start | 峰值电流、电池最低电压、5 V最低值 / Peak current, battery and 5 V minima | 最大记录率，5次 / Highest log rate, five trials | 待测 / Pending |
| E-09 | 最大转向 / Full steering | 舵机峰值、是否抖动/嗡鸣 / Servo peak, jitter/buzz | 架空，左右各5次 / Lifted, five each side | 待测 / Pending |
| E-10 | GPIO/PWM映射 / GPIO/PWM mapping | 物理排针、gpiochip/line、PWM chip/channel、overlay / Header, gpiochip/line, PWM chip/channel and overlay | 排针图+设备树+枚举三方核对 / Header + device tree + enumeration | 待冻结 / Pending freeze |
| E-11 | 3.3 V逻辑 / 3.3 V logic | 驱动器阈值、有效电平、空载波形 / Driver threshold, active level and unloaded waveform | 资料核对+示波器 / Documentation + oscilloscope | 待核 / Pending |

## D. 视觉与软件 / Vision and Software

| ID | 证据 / Evidence | 必须记录 / Required Record | 验收方法 / Acceptance Method | 状态/结果 / Status or Result |
|---|---|---|---|---|
| S-01 | UVC枚举 / UVC enumeration | 设备名、VID:PID、模式、FPS / Device, VID:PID, modes, FPS | 保存系统命令输出 / Save command output | 待板端 / Pending |
| S-02 | 相机标定 / Camera calibration | 矩阵、畸变、图像数、重投影误差 / Matrix, distortion, image count, reprojection error | 棋盘格，多姿态 / Checkerboard, varied poses | 待测 / Pending |
| S-03 | 安装位姿 / Installation pose | 高度、俯仰、横向偏置、ROI / Height, pitch, lateral offset, ROI | 量具+照片 / Measurement + photo | 待测 / Pending |
| S-04 | 颜色识别 / Colour recognition | 红/绿TP、FN、FP、召回、误检 / Red/green TP, FN, FP, recall, false positives | 分层样本集 / Stratified dataset | 待测 / Pending |
| S-05 | 延迟 / Latency | 均值、P95、最大端到端延迟 / Mean, P95, max end-to-end latency | 时间戳或高速录像 / Timestamps or high-speed video | 待测 / Pending |
| S-06 | 稳定性 / Stability | 30 min FPS、温度、掉帧、断连、5 V / 30 min FPS, temperature, drops, disconnects, 5 V | 固定版本连续运行 / Fixed-version endurance | 待测 / Pending |
| S-07 | GPIO/PWM边界输出 / GPIO/PWM boundary output | `-100/0/+100`及越界值对应占空比、DIR和舵机脉宽 / Duty, DIR and steering pulses for boundary/out-of-range values | G-04抬轮波形 / Lifted G-04 waveforms | 程序已实现，待硬件测 / Implemented; hardware test pending |
| S-08 | 250 ms控制更新看门狗 / 250 ms control-update watchdog | 五次实际停车时间、均值、最大值 / Five stop times, mean and maximum | 停止控制更新，示波/日志/视频 / Stop control updates; trace/log/video | 待测 / Pending |
| S-09 | 故障后恢复 / Post-fault recovery | 不自动运动；重新按键后才恢复 / No automatic motion; recover only after button re-arm | G-05/G-06故障注入 / G-05/G-06 fault injection | 待测 / Pending |
| S-10 | CW/CCW与障碍 / CW/CCW and obstacles | 通过侧、碰撞、失败、时间 / Passing side, contacts, failures, time | 两方向、红绿组合 / Both directions and colour combinations | 待测 / Pending |
| S-11 | 连续回合 / Consecutive laps | 至少10回合逐回合记录 / At least ten per-run records | 冻结提交与参数 / Frozen commit and parameters | 待测 / Pending |
| S-12 | 停车与圈数 / Parking and lap count | 状态机、成功率、边界场景 / State machine, success rate, edge cases | 独立功能+完整赛程 / Unit and full-run tests | 尚未完成 / Not implemented |
| S-13 | 进程退出清理 / Process-exit cleanup | 异常、Ctrl+C和正常退出均PWM归零/禁用 / PWM zero/disabled on exception, Ctrl+C and normal exit | G-09波形与日志 / G-09 waveform and log | 待测 / Pending |
| S-14 | 单板冻结边界 / Single-board freeze boundary | 主循环、看门狗线程、用户态进程、GPIO/PWM异常的输出状态 / Output state for loop, watchdog, process and GPIO/PWM faults | 抬轮、限流、可立即断电故障注入 / Lifted, current-limited fault injection | 待测 / Pending |

## E. 可复现性与提交 / Reproducibility and Submission

| ID | 项目 / Item | 通过条件 / Pass Condition | 状态 / Status |
|---|---|---|---|
| R-01 | README | ≥5000字符且首页可找到全部核心证据 / ≥5,000 characters and all evidence discoverable | 已达到篇幅，持续核对链接 / Length met; links checked continuously |
| R-02 | 有效提交 / Meaningful commits | 主分支至少3条不同工程主题的明确提交 / At least three clear main-branch engineering commits | 由队伍完成 / Team action required |
| R-03 | 冻结版本 / Frozen versions | OS、内核、设备树、Python、OpenCV、NumPy、python-periphery、GPIO配置和镜像SHA-256 / OS, kernel, device tree, Python, OpenCV, NumPy, python-periphery, GPIO config and image SHA-256 | 待板端 / Pending |
| R-04 | 陌生人复现 / Independent reproduction | 未参与编程者仅看仓库完成GPIO/PWM枚举、DRY_RUN、架空启动与超时停车 / Non-programmer completes GPIO/PWM enumeration, DRY_RUN, lifted start and timeout using repo only | 待做 / Pending |
| R-05 | 视频映射 / Video mapping | 日期、硬件、提交、参数、成功回合与YouTube一致 / Date, hardware, commit, parameters and laps match YouTube | 待补元数据 / Metadata pending |
| R-06 | 截止快照 / Deadline snapshot | 公共链接、提交SHA、截图、PDF和规则版本归档 / Public link, SHA, screenshot, PDF and rule version archived | 提交前 / Before submission |

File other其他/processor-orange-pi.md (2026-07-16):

# Orange Pi Zero 3W 4GB 车载计算与控制平台 / Onboard Computing and Control Platform

> 当前版本由Orange Pi同时完成视觉、决策和GPIO/PWM执行；Arduino属于上一版本且不安装。 / In the current version, the Orange Pi performs vision, decisions and GPIO/PWM execution; Arduino belongs to the previous version and is not installed.

## 1. 角色 / Role

Orange Pi接收USB摄像头画面，运行OpenCV视觉、方向判断、红绿障碍策略、恢复逻辑和安全状态机，并直接通过GPIO/PWM控制物理按钮输入、转向舵机和PWM/DIR电机驱动器。比赛运行不依赖互联网、云服务、手机或无线遥控。

The Orange Pi receives USB-camera frames, runs OpenCV vision, direction detection, red-green obstacle strategy, recovery logic and the safety state machine, and directly controls the physical button input, steering servo and PWM/DIR motor driver through GPIO/PWM. Competition operation does not depend on the Internet, cloud services, a phone or wireless remote control.

## 2. 已记录配置 / Recorded Configuration

团队当前使用 **Orange Pi Zero 3W 4GB**。采购信息记录全志A733八核平台、4 GB内存、USB、Wi-Fi 6、蓝牙5.4、Mini HDMI 2.0和PCIe 3.0等信息。比赛真正使用的能力是USB主机、Linux/OpenCV、本地存储、GPIO和PWM；无线功能必须关闭。处理器宣传参数不能替代最终实机枚举与压力测试。

The team currently uses an **Orange Pi Zero 3W 4GB**. Purchase records note an Allwinner A733 octa-core platform, 4 GB memory, USB, Wi-Fi 6, Bluetooth 5.4, Mini HDMI 2.0 and PCIe 3.0. Competition-relevant capabilities are USB host, Linux/OpenCV, local storage, GPIO and PWM; wireless functions must be disabled. Advertised processor specifications do not replace final hardware enumeration and stress testing.

## 3. 选择理由与取舍 / Selection Rationale and Trade-offs

| 选择 / Choice | 优点 / Benefit | 代价 / Cost | 缓解 / Mitigation |
|---|---|---|---|
| Linux SBC处理视觉 / Linux SBC for vision | OpenCV生态、调试工具、USB摄像头支持 / OpenCV ecosystem, diagnostics and USB-camera support | 启动和调度不如微控制器确定 / Less deterministic startup and scheduling than an MCU | 固定镜像、禁用无关服务、离线启动测试 / Freeze image, disable services, test offline startup |
| 同板GPIO/PWM执行 / Same-board GPIO/PWM execution | 减少控制器、线束、协议和板间延迟 / Fewer controllers, wires, protocols and inter-board latency | 视觉与执行共享故障域 / Vision and execution share a fault domain | 默认停车、物理按钮、进程看门狗、故障注入与硬件失效保护评估 / Stopped default, physical button, process watchdog, fault injection and hardware-fail-safe assessment |
| USB单摄像头 / Single USB camera | 同时获得边界、颜色和方向信息 / Borders, colour and direction in one sensor | 光照、畸变、遮挡和掉帧敏感 / Sensitive to lighting, distortion, occlusion and frame drops | 标定、固定安装、低置信度减速、帧超时 / Calibration, rigid mount, low-confidence slowdown, frame timeout |

## 4. GPIO/PWM资源冻结 / GPIO/PWM Resource Freeze

Orange Pi的物理排针号、SoC管脚名、设备树功能、libgpiod line号以及PWM chip/channel并不等价。当前仓库故意把实际映射设为 `-1`，避免在未确认的板卡或镜像上误动作。

Orange Pi physical-header numbers, SoC pin names, device-tree functions, libgpiod line numbers and PWM chip/channels are not interchangeable. The repository intentionally sets real mappings to `-1` to prevent unintended motion on an unverified board or image.

最终冻结表 / Final freeze table:

| 功能 / Function | 物理排针 / Header Pin | gpiochip/line或PWM chip/channel | 复用/overlay | 有效电平 / Active Level | 证据 / Evidence |
|---|---|---|---|---|---|
| 电机方向 / Motor direction | 待填 / Pending | 待填 / Pending | 待填 / Pending | 待填 / Pending | gpioinfo + 示波器 / gpioinfo + scope |
| 电机速度PWM / Motor-speed PWM | 待填 / Pending | 待填 / Pending | 待填 / Pending | 高有效待核 / Verify active high | sysfs + scope |
| 舵机PWM / Steering PWM | 待填 / Pending | 待填 / Pending | 待填 / Pending | 正脉冲 / Positive pulse | sysfs + scope |
| 启动/停止按钮 / Start-stop button | 待填 / Pending | 待填 / Pending | GPIO input | 外部上拉、按下为低 / External pull-up, active low | gpioinfo + multimeter |

冻结命令 / Freeze commands:

```bash
uname -a
cat /etc/os-release
gpiodetect
gpioinfo
ls -l /dev/gpiochip*
find /sys/class/pwm -maxdepth 3 -type f -o -type l
```

每次更换镜像、内核、设备树、排针或overlay后必须重新核验。不能把其他Orange Pi型号或不同镜像中的管脚号直接复制到本车。

Reverify after any image, kernel, device-tree, header or overlay change. Never copy pin numbers from another Orange Pi model or a different image directly into this vehicle.

## 5. 直接控制实现 / Direct-Control Implementation

`orange_pi_gpio.py`使用python-periphery访问字符设备GPIO与内核PWM。硬件访问延迟导入，因此 `enabled=false` 的DRY_RUN不需要打开硬件设备。现行职责如下：

`orange_pi_gpio.py` uses python-periphery for character-device GPIO and kernel PWM. Hardware access is imported lazily, so DRY_RUN with `enabled=false` opens no hardware devices. Current responsibilities are:

- GPIO输入去抖并实现物理启动/停止。 / Debounce the GPIO input for physical start/stop.
- GPIO输出电机方向。 / Output motor direction through GPIO.
- PWM输出电机速度和舵机脉宽。 / Output motor speed and steering pulse width through PWM.
- 把逻辑量限制在 `-100...100`，把舵机限制在配置脉宽范围。 / Bound logical values to `-100...100` and steering to configured pulse widths.
- 方向改变前先把电机占空比置零。 / Set motor duty to zero before changing direction.
- 250 ms无新控制更新后停车并要求重新授权。 / Stop and require re-arming after 250 ms without a fresh update.
- 异常、Ctrl+C和退出时清零、禁用并关闭资源。 / Zero, disable and close resources on exceptions, Ctrl+C and exit.

## 6. 电气约束 / Electrical Constraints

1. Orange Pi GPIO仅为逻辑信号，不得给舵机、电机或驱动器动力端供电。 / Orange Pi GPIO is logic-only and must not power the servo, motor or driver power stage.
2. Orange Pi使用独立稳压 **5 V / 3 A** 支路，舵机使用独立4.5–7 V支路，电机使用动力支路。 / Use an independent regulated **5 V / 3 A** Orange Pi branch, a separate 4.5–7 V servo branch and a motor-power branch.
3. 所有控制信号共地；大电流回流短且与USB、GPIO和摄像头线分开。 / All control signals share ground; high-current returns are short and separated from USB, GPIO and camera wiring.
4. 电机驱动器方向/PWM输入必须确认兼容3.3 V；否则使用合适的电平转换或缓冲。 / Confirm motor-driver direction/PWM inputs accept 3.3 V; otherwise use an appropriate level shifter or buffer.
5. 物理按钮使用外部上拉，避免依赖未验证的内部偏置。 / Use an external pull-up for the physical button rather than an unverified internal bias.
6. 最终保险、线径、稳压额定值和散热必须依据实测电流与温升确定。 / Determine fuse, wire gauge, regulator rating and cooling from measured current and temperature rise.

## 7. 启动与运行基线 / Startup and Runtime Baseline

| 项目 / Item | 要求 / Requirement | 证据 / Evidence |
|---|---|---|
| 冷启动 / Cold boot | 无网络、无人机交互，进入停车状态 / No network or user interaction; enter stopped state | 五次冷启动视频与日志 / Five cold-boot videos and logs |
| 摄像头枚举 / Camera enumeration | 固定设备识别策略，避免 `/dev/videoN`漂移 / Stable device identification, not fragile `/dev/videoN` assumptions | UVC枚举 / UVC enumeration |
| 配置 / Configuration | 缺失或非法映射时拒绝启用 / Refuse enable on missing or invalid mapping | G-01日志 / G-01 log |
| 按钮 / Button | 上电不运动，去抖后才授权 / No power-on motion; arm only after debounce | G-02/G-03 |
| 看门狗 / Watchdog | 控制更新年龄超过250 ms停车 / Stop when control age exceeds 250 ms | G-05五次测量 / Five G-05 measurements |
| 退出 / Exit | 电机PWM归零、舵机回中、PWM禁用 / Motor PWM zero, steering centred, PWM disabled | G-09 |
| 稳定性 / Stability | 30分钟无重启、无资源泄漏、温度可接受 / 30 minutes without restart or resource leak; acceptable temperature | R-03日志 / R-03 log |

## 8. 故障域与硬件保护决策 / Fault Domain and Hardware Protection Decision

进程看门狗与控制进程位于同一Linux系统。它能在主控制循环停止更新时独立调用停车，但若内核、PWM驱动、供电或整板冻结，就不一定有机会执行。这是从双控制器架构切换到单板直控后必须公开说明的取舍。

The watchdog and controller share one Linux system. It can call stop independently when the main control loop stops updating, but may not run if the kernel, PWM driver, power or whole board freezes. This trade-off must be stated openly after moving from a two-controller architecture to single-board direct control.

关闭该风险前需完成：

Before closing this risk:

1. 抬轮、限流和可立即断电条件下完成进程挂起、线程停止、设备异常和受控系统失联测试。 / Test process suspension, stopped threads, device errors and controlled system unresponsiveness with lifted wheels, current limiting and immediate power removal.
2. 记录失效时PWM是否保持最后值、归零或禁用。 / Record whether PWM holds the last value, goes to zero or disables on each fault.
3. 依据结果决定是否增加独立硬件使能门、驱动器EN下拉、硬件看门狗或常闭急停。 / Decide on an independent enable gate, driver-EN pull-down, hardware watchdog or normally-closed emergency stop from the results.
4. 在FMEA、接线图、BOM与测试表中同步最终决定。 / Synchronise the final decision in the FMEA, wiring diagram, BOM and test table.

## 9. 上一版本说明 / Previous-Version Note

上一版本由Orange Pi运行视觉，通过115200 baud文本串口向Arduino发送转向和速度，Arduino负责D2/D6/D7/D8输出。该架构、配置和程序保留在仓库中用于说明迭代过程，但不应出现在当前装车、当前运行命令或当前验收结果中。

The previous version ran vision on the Orange Pi and sent steering and speed over a 115200-baud text serial link to an Arduino that owned D2/D6/D7/D8 outputs. This architecture, configuration and code remain for iteration history but must not appear in current assembly, run commands or acceptance results.

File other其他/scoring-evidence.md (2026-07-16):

# 2026技术文档评分证据地图 / 2026 Engineering-Documentation Evidence Map

> 审核日期：2026-07-16。本文件依据《2026未来工程师无人驾驶赛季规则》附录C和《2026未来工程师—技术文档评审标准》整理。它是裁判快速入口，不替代各技术文件。所有“待实测”内容均不得以推测值替代。  
> Audit date: 2026-07-16. This map follows Appendix C of the 2026 Future Engineers Autonomous Driving rules and the 2026 engineering-documentation rubric. It is a judge-facing index, not a replacement for the technical files. Any item marked “measurement pending” must not be replaced by an assumed value.

## 1. 评分逻辑 / Scoring Logic

技术文档共五个维度，每项为0、2、4或6分，满分30分。6分要求的不只是“有文件”，还要求选型理由、约束、方案取舍、测试、迭代和可复现证据形成闭环。规则还要求结构化工程日志采用PDF或类似可归档格式，并要求GitHub至少包含代码、CAD、接线说明和相关技术材料。

The documentation has five dimensions, each scored 0, 2, 4 or 6, for a maximum of 30. A 6-point result requires more than file presence: selection rationale, constraints, trade-offs, tests, iteration and reproducible evidence must form a closed engineering chain. The rules also require a structured engineering log in PDF or another archival format and a GitHub repository containing code, CAD, wiring information and relevant technical material.

本仓库按“规则要求 → 设计主张 → 证据文件 → 验证状态 → 下一项证据”组织。下表中的“6分目标”表示提交前必须完成的证据包，不是对裁判结果的预判。

This repository is organised as “rule requirement → design claim → evidence file → validation state → next evidence”. A “6-point target” means the evidence package required before submission; it is not a prediction of the judges’ score.

## 2. 五维总览 / Five-Dimension Overview

| 维度 / Dimension | 已有核心证据 / Existing Core Evidence | 当前证据强度 / Current Evidence Strength | 达到6分仍需 / Still Required for a 6-Point Claim |
|---|---|---|---|
| 1. 移动性能与机械设计 / Mobility and mechanical design | [首页机械章节](../README.md#3-移动性与机械设计--mobility-and-mechanical-design)、[机械分析](mechanical-analysis.md)、[模型与DXF](../models模型/README.md)、[测试表](tests.md#4-机械电气与整车--mechanical-electrical-and-full-vehicle) | 已说明阿克曼、四驱、差速、几何和理论速度；有层板DXF / Ackermann, four-wheel drive, differentials, geometry, theoretical speed and a plate DXF are documented | 最终装车尺寸/质量、舵角、左右转弯半径、速度/扭矩实测、支架图纸、测试前后机械迭代照片 / Final dimensions, mass, steering angles, left/right radius, speed/torque measurements, mount drawings and before/after iteration evidence |
| 2. 动力与传感器架构 / Power and sensor architecture | [接线图](../schemes原理图/wiring.md)、[正式系统图](../schemes原理图/system-wiring.png)、[视觉与摄像头](camera-vision.md)、[标定指南](calibration-guide.md)、[FMEA](FMEA.md) | 已明确纯视觉架构、分支供电、共地、噪声和标定流程 / Vision-only architecture, power branches, common ground, interference and calibration method are documented | 实物驱动器/电池/稳压/舵机型号，支路典型与峰值电流、最低电压、保险规格、相机安装实测、故障注入结果 / Exact hardware models, branch currents, minimum voltage, fuse rating, camera pose and fault-injection results |
| 3. 软件架构与障碍策略 / Software and obstacle strategy | [软件架构](software-architecture.md)、[`bev_segmentation.py`](../src源代码/bev_segmentation.py)、[`orange_pi_gpio.py`](../src源代码/orange_pi_gpio.py)、[测试流程](tests.md) | 已有模块说明、视觉恢复、GPIO安全状态机、默认禁用和250 ms进程看门狗 / Module documentation, vision recovery, GPIO safety state, disabled default and 250 ms process watchdog are present | 真实GPIO/PWM映射与波形、相机标定、停车区与圈数逻辑、识别率/误检率/延迟/FPS、连续回合数据、Linux/PWM冻结边界和最终视频对应提交 / Real GPIO/PWM mapping and waveforms, calibration, parking/lap logic, recognition/latency/FPS metrics, consecutive laps, Linux/PWM freeze boundary and a video-matched commit |
| 4. 系统思维与工程决策 / Systems thinking and engineering decisions | [工程日志](engineering-log.md)、[可归档PDF](engineering-log.pdf)、[FMEA](FMEA.md)、[BOM与选型](BOM.md)、[变更记录](CHANGELOG.md) | 已记录从超声波、Arduino串口执行到当前单板GPIO直控的迭代，以及减少器件与扩大故障域的取舍 / Evolution from ultrasonic and Arduino serial execution to current single-board GPIO control, including the fewer-parts/larger-fault-domain trade-off, is documented | 用实测数据完成至少三条“选择X而非Y”的结论，并给出改动前/后数据 / At least three measured “X rather than Y” decisions with before/after data |
| 5. 可复现性与GitHub质量 / Reproducibility and GitHub quality | [README](../README.md)、[复现指南](reproduction-guide.md)、[源代码索引](../src源代码/README.md)、[测试](tests.md)、[版本记录](CHANGELOG.md) | 目录沿用官方模板；README超过5000字符；含代码、DXF、接线、测试与版本说明 / Official-template structure; README exceeds 5,000 characters; code, DXF, wiring, tests and version notes are present | 主分支至少3条内容明确的提交、车辆六视图、趣味团队照、最终CAD、冻结软件版本/镜像校验值、陌生队员复现记录 / At least three meaningful main-branch commits, six vehicle views, informal team photo, final CAD, frozen software/image checksums and an independent reproduction record |

## 3. 维度1：移动性能与机械设计 / Dimension 1: Mobility and Mechanical Design

### 3.1 设计主张 / Design Claim

车辆采用汽车式阿克曼转向、前后差速器和中央传动轴四轮驱动。该方案的目标是减少刚性四轮转向时的轮胎侧滑，提高直线稳定性，并让转向轨迹连续。代价是轴距、轮距、内外轮转角和舵机行程共同限制最小转弯半径，机械间隙与左右不对称会直接转化为路径误差。

The vehicle uses automotive Ackermann steering, front and rear differentials and shaft-driven four-wheel drive. The design aims to reduce tyre scrub, improve straight-line stability and produce continuous turning trajectories. The trade-off is that wheelbase, track width, inner/outer steering angles and servo travel jointly limit turning radius, while mechanical play and left/right asymmetry directly become path errors.

### 3.2 计算与论证入口 / Calculation and Rationale Entry Points

- 底盘规格、理论车速、牵引力与转向关系：[机械分析](mechanical-analysis.md)。 / Chassis data, theoretical speed, traction and steering relationships: [mechanical analysis](mechanical-analysis.md).
- 层板制造文件与机械复现边界：[模型目录](../models模型/README.md)。 / Plate manufacturing file and mechanical reproduction boundaries: [models](../models模型/README.md).
- 规格值与装车实测分开记录：[测试流程](tests.md)。 / Catalogue values and assembled measurements are separated in the [test procedure](tests.md).

### 3.3 满分证据包 / Full-Score Evidence Package

1. 装车完成后测量长、宽、高、总质量、重心大致位置和离地间隙，并拍摄测量过程。 / Measure final length, width, height, mass, approximate centre of gravity and ground clearance, with photographs of the method.
2. 架空逐步增加舵机角度，记录左/中/右安全角，不以舵机嗡鸣作为限位。 / Increase servo angle with wheels lifted and record safe left/centre/right limits; do not use servo buzzing as a limit indicator.
3. 以相同电量、轮胎和地面测量左右最小转弯半径，各做5次，记录均值、范围和异常。 / Measure left and right minimum turning radii five times each with the same battery, tyres and surface; record mean, range and anomalies.
4. 对至少5个速度命令做固定距离计时，记录平均速度、停止距离和电池电压。 / Time a fixed distance for at least five speed commands and record mean speed, stopping distance and battery voltage.
5. 用“问题—修改—结果”展示至少一次机械迭代，例如相机支架刚度、转向连杆对称性或线束干涉。 / Show at least one mechanical iteration as “problem—change—result”, such as camera-mount stiffness, steering-link symmetry or wiring interference.

## 4. 维度2：动力与传感器架构 / Dimension 2: Power and Sensor Architecture

### 4.1 架构主张 / Architecture Claim

当前车辆只以USB彩色摄像头感知赛道和红绿障碍。Orange Pi同时完成视觉、决策和GPIO/PWM执行。选择单摄像头的优势是信息密度高、可同时判断边线、方向和颜色，且机械布置简洁；选择单板直控则减少控制器、线束和板间协议延迟。代价是缺少独立距离冗余，且视觉与执行共享故障域，因此必须通过标定、固定安装、低置信度降速、控制更新看门狗、故障注入和独立硬件失效保护评估进行补偿。

The current vehicle uses a USB colour camera as its only track and red-green obstacle sensor. The Orange Pi performs vision, decisions and GPIO/PWM execution. One camera offers high information density and interprets borders, direction and colour with simple mechanical layout, while single-board direct control reduces controllers, wiring and inter-board protocol latency. The costs are no independent range redundancy and a shared vision/execution fault domain, requiring calibration, rigid mounting, low-confidence slowdown, a control-update watchdog, fault injection and an independent-hardware-fail-safe assessment.

### 4.2 电源边界 / Power Boundaries

- 电机动力、Orange Pi独立5 V/3 A和舵机4.5–7 V使用独立规划支路；执行器负载不得由Orange Pi排针供电。 / Motor power, independent Orange Pi 5 V/3 A and servo 4.5–7 V use planned branches; actuator loads must not be powered from the Orange Pi header.
- 大电流回流与USB/GPIO信号分开走线但控制地相连；最终保险、线径和稳压额定值必须由实物数据确定。 / High-current returns are routed separately from USB/GPIO signals while control grounds remain common; final fuse, wire gauge and regulator ratings must follow actual hardware data.
- 正式图纸：[PNG接线图](../schemes原理图/system-wiring.png)与[接线说明](../schemes原理图/wiring.md)。 / Formal drawing: [PNG wiring diagram](../schemes原理图/system-wiring.png) and [wiring guide](../schemes原理图/wiring.md).

### 4.3 满分证据包 / Full-Score Evidence Package

1. 拍摄电池、稳压、驱动器、舵机标签和全车布线，填写准确型号与额定值。 / Photograph labels and full wiring for the battery, regulators, driver and servo; enter exact models and ratings.
2. 分别记录静止、视觉运行、直行、最大转向、电机启动时的电池电压/电流，以及Orange Pi 5 V最低值。 / Record battery voltage/current and minimum Orange Pi 5 V while idle, running vision, driving straight, steering fully and starting the motor.
3. 用 `P=U×I` 计算每支路典型/峰值功率和至少25%的设计余量；根据峰值选择保险和稳压。 / Calculate typical/peak branch power with `P=U×I` and at least 25% design margin; select fuse and regulator from peak values.
4. 标定相机内参、畸变、安装高度/俯仰、ROI、曝光、白平衡和HSV阈值。 / Calibrate intrinsics, distortion, height/pitch, ROI, exposure, white balance and HSV thresholds.
5. 注入强光、阴影、反光、拔相机、停止控制更新、进程挂起、GPIO/PWM设备异常和5 V压降，记录停车时间、输出状态和恢复条件。 / Inject bright light, shadows, reflections, camera loss, stopped updates, process suspension, GPIO/PWM device errors and 5 V sag; record stopping time, output state and recovery conditions.

## 5. 维度3：软件架构与障碍应对策略 / Dimension 3: Software and Obstacle Strategy

### 5.1 模块与责任 / Modules and Responsibilities

| 层 / Layer | 文件 / File | 责任 / Responsibility | 安全边界 / Safety Boundary |
|---|---|---|---|
| 图像预处理 / Image preprocessing | [`bev_road.py`](../src源代码/bev_road.py) | 亮度、道路候选、实验BEV、连通域 / Brightness, road candidates, experimental BEV and components | 当前不是最终标定BEV / Not yet a final calibrated BEV |
| 视觉与策略 / Vision and strategy | [`bev_segmentation.py`](../src源代码/bev_segmentation.py) | 红绿HSV、道路密度、CW/CCW、恢复和约20 Hz控制更新 / Red-green HSV, road density, CW/CCW, recovery and ~20 Hz control updates | 初始/退出速度为0；参数需实车冻结 / Zero initial/exit speed; parameters require vehicle freeze |
| GPIO/PWM安全执行 / GPIO/PWM safe execution | [`orange_pi_gpio.py`](../src源代码/orange_pi_gpio.py) | 按钮、GPIO/PWM、限幅、方向切换保护和250 ms超时 / Button, GPIO/PWM, limits, direction-change protection and 250 ms timeout | 默认禁用；上电不动；故障后需重新按键 / Disabled by default; no power-on motion; re-arm after fault |

### 5.2 当前GPIO/PWM执行契约 / Current GPIO/PWM Execution Contract

- 输入：同一进程内调用 `set_control(steer, speed)`，两项逻辑范围为 `-100...100`。 / Input: in-process `set_control(steer, speed)` calls with both logical values in `-100...100`.
- 更新：视觉循环约每50 ms提交一次新目标，输出层用单调时钟记录最近更新。 / Update: the vision loop submits a target about every 50 ms; the output layer records the latest update on a monotonic clock.
- 授权：上电处于 `WAIT_START`，去抖后的物理按钮才允许执行。 / Arming: power-up enters `WAIT_START`; only a debounced physical press enables execution.
- 安全超时：250 ms无新控制更新，电机PWM归零、舵机回中并进入 `CONTROL_FAILSAFE`。 / Timeout: after 250 ms without a fresh update, motor PWM goes to zero, steering centres and state becomes `CONTROL_FAILSAFE`.
- 恢复：必须重新按物理按钮；方向变化前电机PWM先归零。 / Recovery: physical re-arm is required; motor PWM is zeroed before direction changes.
- 边界：同进程看门狗不能保证覆盖Linux或PWM整体冻结。 / Boundary: the same-process watchdog cannot guarantee coverage of a complete Linux or PWM freeze.

### 5.3 满分证据包 / Full-Score Evidence Package

1. 以流程图/状态机说明道路、红绿障碍、恢复、停车区、圈数和最终停车。 / Document track, red-green obstacles, recovery, parking zone, lap counting and final stop with flow/state diagrams.
2. 冻结全部参数和软件版本，记录命令行、配置文件和镜像SHA-256。 / Freeze all parameters and software versions; record command line, configuration and image SHA-256.
3. 按颜色、距离、中心/边缘、光照和同时出现分组测试，报告召回率、误检率、通过侧正确率。 / Test by colour, distance, centre/edge, lighting and simultaneous objects; report recall, false-positive rate and passing-side accuracy.
4. 报告端到端延迟的均值、95百分位和最大值，以及FPS、掉帧和30分钟稳定性。 / Report mean, 95th-percentile and maximum end-to-end latency, plus FPS, dropped frames and 30-minute stability.
5. 连续完成至少10个完整回合，记录每回合时间、碰撞、人工干预、失败类型和唯一改动。 / Complete at least ten consecutive full laps and record time, contacts, intervention, failure type and the single change between runs.

## 6. 维度4：系统思维与工程决策 / Dimension 4: Systems Thinking and Engineering Decisions

### 6.1 已明确约束 / Defined Constraints

- 规则约束：自动驾驶、启动要求、比赛通信限制、车辆尺寸与工程文件截止时间。 / Rule constraints: autonomy, start requirement, competition communication limits, vehicle dimensions and documentation deadline.
- 感知约束：仅摄像头，无超声波和编码器冗余。 / Sensing constraint: camera only, with no ultrasonic or encoder redundancy.
- 机械约束：260×140×85 mm基础底盘、174 mm轴距、123 mm轮距、475 mm标称最小转弯半径。 / Mechanical constraints: 260×140×85 mm base chassis, 174 mm wheelbase, 123 mm track and 475 mm rated minimum radius.
- 动力约束：电机启动与舵机峰值可能造成压降；Orange Pi需要稳定5 V支路。 / Power constraints: motor start and servo peaks may cause sag; the Orange Pi needs a stable 5 V branch.
- 算力约束：480p/30 FPS输入，CPU/OpenCV为可复现基线，任何NPU优化都必须单独验证。 / Compute constraints: 480p/30 FPS input, CPU/OpenCV as the reproducible baseline; any NPU optimisation requires separate validation.
- 时间约束：必须在截止日期前把实测、照片、提交和PDF归档。 / Schedule constraint: measurements, photographs, commits and PDF must be archived before the deadline.

### 6.2 当前方案取舍 / Current Trade-offs

| 选择 / Choice | 放弃或代价 / Alternative or Cost | 选择理由 / Rationale | 验证状态 / Validation |
|---|---|---|---|
| 阿克曼而非差速转向 / Ackermann rather than skid steering | 机构和标定更复杂 / More mechanics and calibration | 更接近汽车、直线稳定、轮胎侧滑小 / Automotive motion, straight stability, reduced scrub | 理论说明完成；实测待补 / Rationale complete; measurements pending |
| Orange Pi单板GPIO/PWM直控 / Orange Pi single-board direct GPIO/PWM | 视觉与执行共享故障域 / Vision and execution share a fault domain | 减少控制器、线束和协议延迟，所有输出集中审查 / Fewer controllers, wires and protocol latency; centralised output review | 代码闭环；映射、波形、整车与冻结边界待测 / Code chain present; mapping, waveforms, vehicle and freeze boundary pending |
| 单USB彩色摄像头 / One USB colour camera | 无独立距离冗余，受光照影响 / No range redundancy; lighting sensitivity | 同时获取赛道几何和红绿颜色，布置简单 / Track geometry and colour from one sensor, simple layout | 参数与识别指标待实测 / Parameters and metrics pending |
| 本地GPIO/PWM而非板间通信 / Local GPIO/PWM rather than inter-board communication | 依赖Linux GPIO/PWM正确配置 / Depends on correct Linux GPIO/PWM configuration | 无无线、无板间协议，延迟路径短 / No radio or inter-board protocol; short latency path | 模板默认禁用；实际资源待冻结 / Template disabled by default; actual resources pending |
| 开环速度而非编码器PI / Open-loop speed rather than encoder PI | 电量和负载导致速度变化 / Speed varies with battery and load | 当前车辆明确不读取编码器，降低集成复杂度 / Current vehicle does not read encoders; simpler integration | 必须用速度映射与停车距离补偿 / Requires speed/stopping-distance mapping |

### 6.3 数据驱动结论模板 / Data-Driven Decision Template

每条最终决策必须写成：**约束/问题 → 候选X与Y → 同条件测试 → 量化结果 → 选择 → 新风险与缓解 → 对应提交和证据。** 例如只有在完成同电量对比后，才能写“选择速度上限X而非Y，因为95%停车距离由A降至B且完整回合时间仍满足目标”。

Each final decision must follow: **constraint/problem → candidates X and Y → controlled test → quantified result → selection → new risk and mitigation → matching commit and evidence.** For example, only after a same-battery comparison may the team state, “speed limit X was selected over Y because the 95th-percentile stopping distance fell from A to B while lap time still met the target.”

## 7. 维度5：可复现性与GitHub质量 / Dimension 5: Reproducibility and GitHub Quality

### 7.1 规则核心检查 / Core Rule Checks

| 要求 / Requirement | 仓库位置 / Repository Location | 状态 / Status |
|---|---|---|
| README不少于5000字符 / README at least 5,000 characters | [`README.md`](../README.md) | 已满足篇幅；继续以内容质量为准 / Length satisfied; quality still governs |
| 至少3条有效提交 / At least three meaningful commits | Git历史 / Git history | 主分支提交说明仍需由队伍整理；不要把全部修改压成一次提交 / Main-branch messages still need team action; do not squash all work into one commit |
| 代码 / Code | [`src源代码/`](../src源代码/README.md) | 已有视觉、GPIO/PWM执行与默认禁用配置模板 / Vision, GPIO/PWM execution and disabled-by-default configuration template present |
| CAD / CAD | [`models模型/`](../models模型/README.md) | 有层板DXF；最终支架CAD待补 / Plate DXF present; final mount CAD pending |
| 接线 / Wiring | [`schemes原理图/`](../schemes原理图/wiring.md) | 有PNG/SVG图和文字接线；实物型号待核 / PNG/SVG and written wiring present; hardware models pending |
| 测试流程 / Test procedure | [`tests.md`](tests.md) | 流程与表格齐全；真实数据待录入 / Procedure and tables present; actual data pending |
| 版本日志 / Version log | [`CHANGELOG.md`](CHANGELOG.md) | 已有阶段记录；需与提交对应 / Stage log present; map it to commits |
| 结构化可归档日志 / Archival engineering log | [`engineering-log.pdf`](engineering-log.pdf) | 已生成；最终实测后重新生成 / Generated; rebuild after final measurements |
| 车辆六视图 / Six vehicle views | [`v-photos车辆照片/`](../v-photos车辆照片/README.md) | 待拍 / Pending |
| 团队照片与视频 / Team photo and video | [团队照片](../t-photos团队照片/README.md)、[视频](../video视频/video.md) | 正式照和视频已有；趣味团队照待补 / Official photo and video present; informal photo pending |

### 7.2 独立复现验收 / Independent Reproduction Acceptance

由一名未编写程序的队员仅阅读仓库完成：找到接线、枚举GPIO/PWM、核对物理排针与line/channel、安装依赖、复制默认禁用配置、解释状态机、完成DRY_RUN与架空G-01至G-10、触发控制更新超时并定位日志。记录用时、卡住步骤和文档修改。只有不需要口头补充且所有真实映射有证据时，才可声明“完全可复现”。

A member who did not write the software must use only the repository to locate wiring, enumerate GPIO/PWM, map the physical header to line/channel values, install dependencies, copy the disabled configuration, explain the state machine, complete DRY_RUN and lifted-wheel G-01 through G-10, trigger a control-update timeout and locate logs. Record time, blocked steps and resulting documentation edits. “Fully reproducible” may be claimed only when no verbal additions are required and all real mappings have evidence.

## 8. 提交前红线 / Pre-Submission Red Lines

- 不把目录规格、商品页面或理论值写成装车实测。 / Do not present catalogue, listing or theoretical values as assembled measurements.
- 不把存在于仓库中的原型写成“比赛验证通过”。 / Do not describe a repository prototype as competition-validated.
- 不把旧超声波/编码器程序描述为当前车辆传感器。 / Do not describe historical ultrasonic/encoder code as current sensing.
- 不在驱动器、电池、稳压器型号未核实前写入确定型号。 / Do not assert driver, battery or regulator models before verification.
- 不保证“满分”；只提交裁判可独立核验的证据。 / Do not guarantee a full score; submit evidence that judges can independently verify.
- 国际赛提交前复核英文内容、公开链接、截止日期快照和至少一年的仓库公开保留要求。 / Before international submission, verify English content, public links, deadline snapshot and the one-year public repository retention requirement.

## 9. 最终签署 / Final Sign-Off

| 负责人 / Owner | 核验内容 / Verification | 日期 / Date | 提交号/证据 / Commit or Evidence | 签名 / Sign-off |
|---|---|---|---|---|
| 陆昭颖 / Lu Zhaoying | 视觉、状态机、参数、软件版本 / Vision, state machine, parameters, software versions | | | |
| 张隽泽 / Zhang Junze | 尺寸、机械图、转向、六视图 / Dimensions, mechanical drawings, steering, six views | | | |
| 黄鸣博 / Huang Mingbo | 型号、接线、电流、电压、保险、安全 / Models, wiring, current, voltage, fuse, safety | | | |
| 薛源 / Xue Yuan | 规则、视频、提交截止与总体验收 / Rules, video, deadline and final acceptance | | | |

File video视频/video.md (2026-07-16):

# 车辆驾驶演示视频 / Vehicle Driving Demonstration

视频车辆以USB摄像头视觉作为唯一环境感知。 / The demonstrated vehicle uses USB-camera vision as its only environmental sensing method.

## 正式链接 / Official Link

**标题 / Title:** 2026 WRO Future Engineers | 南京博颂学校 BONA SONORITY SCHOOL NANJING | Autonomous Driving Demonstration

**YouTube:** <https://youtu.be/DJcxiJCEFdo>

链接于2026-07-15验证。最终提交前应使用未登录浏览器再次确认公开或“不公开列出”权限。

The link was verified on 2026-07-15. Before final submission, verify public or unlisted access again in a signed-out browser.

观看演示 / Watch demonstration (https://youtu.be/DJcxiJCEFdo)

## 本地文件 / Local File

`南京博颂学校未来工程师1.0演视视频.mp4`

| 项目 / Item | 检查值 / Verified Value |
|---|---:|
| 时长 / Duration | 106.812 s (约1:47 / approximately 1:47) |
| 视频 / Video | 1920×1080, 30 FPS, H.264 |
| 音频 / Audio | AAC |
| 大小 / Size | 91,299,421 bytes (87.07 MiB) |

该版本低于GitHub 100 MB单文件限制。公开观看以YouTube为准；未压缩原片另行备份，不加入仓库。

This version is below GitHub's 100 MB per-file limit. YouTube remains the public viewing source; back up the uncompressed original separately and do not add it to the repository.

## 视频展示要求 / Required Video Content

- 最终车辆与仓库照片一致 / Final vehicle matches repository photographs.
- 启动前停止，独立按钮启动 / Stopped before start and launched by an independent button.
- 自动驾驶片段满足规则时长 / Autonomous segment meets the rule duration.
- 展示直线、转弯、循迹和安全停车 / Shows straights, turns, tracking and safe stopping.
- 若证明障碍赛，展示红绿合规处理 / If used for obstacle proof, shows compliant red-green handling.
- 可判断无人工干预 / Editing still allows verification of no human intervention.
- 链接公开或持链接可访问 / Public or unlisted-accessible link.

## 版本记录 / Version Record

| 项目 / Item | 内容 / Content |
|---|---|
| 学校 / School | 南京博颂学校 / BONA SONORITY SCHOOL NANJING |
| YouTube ID | `DJcxiJCEFdo` |
| 拍摄日期 / Recording date | 待填 / TBD |
| Git提交 / Commit | 待填 / TBD |
| 视觉程序 / Vision program | `bev_segmentation.py`，是否匹配待确认 / match pending |
| 驱动器 / Driver | AT8236或DRV8701，待确认 / AT8236 or DRV8701; pending confirmation |
| 高层 / High level | Orange Pi Zero 3W 4GB |
| 执行控制 / Execution control | Orange Pi GPIO/PWM直接控制；实际映射待补 / Direct Orange Pi GPIO/PWM control; physical mapping pending |
| 电池与速度 / Battery and speed | 待填 / TBD |
| 视觉参数 / Vision parameters | 相机、ROI、HSV、权重、转向待填 / camera, ROI, HSV, weights and steering TBD |
| 其他传感器 / Other sensors | 不使用超声波或编码器 / No ultrasonic or encoder use |
| 场地与成功回合 / Field and successful laps | 待填 / TBD |

提交号用于证明视频行为与仓库代码一致。 / The commit proves that video behaviour matches repository code.

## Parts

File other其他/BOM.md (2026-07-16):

# 物料表与选型依据 / Bill of Materials and Selection Rationale

**当前配置：** USB摄像头是BOM中唯一的环境感知设备；当前不使用超声波或编码器反馈。

**Current configuration:** The USB camera is the only environmental sensor in the BOM; ultrasonic sensing and encoder feedback are not used.

本表区分“资料已确认”和“实物必须复核”的信息。最终装车后，两名队员应交叉确认品牌、型号、电压和数量。

This table separates information confirmed from available material from details that require physical verification. After final assembly, two team members should cross-check brands, models, voltages and quantities.

| 子系统 / Subsystem | 部件 / Component | 当前信息 / Current Information | 数量 / Qty. | 作用 / Purpose | 状态 / Status |
|---|---|---|---:|---|---|
| 机械 / Mechanical | 阿克曼底盘 / Ackermann chassis | 260×140×85 mm基础尺寸记录 / 260×140×85 mm base-size record | 1 | 前轮转向、四驱和差速 / Front steering, four-wheel drive and differentials | 最终装车尺寸待测 / Final assembled size pending |
| 机械 / Mechanical | 二维层板 / 2D plate | `models模型/HSP94182层板.dxf` | 1 set | 主控、摄像头和电源安装 / Controller, camera and power mounting | 文件已入库，实物待核 / File included; hardware pending |
| 计算 / Computing | 视觉计算机 / Vision computer | Orange Pi Zero 3W, Allwinner A733, 4 GB LPDDR5 | 1 | 图像采集、识别和决策 / Image capture, recognition and decisions | SKU确认，实机待验 / SKU confirmed; hardware pending |
| 计算与控制 / Compute and control | 主控与执行控制器 / Main and execution controller | Orange Pi Zero 3W 4GB | 1 | 视觉、策略、GPIO/PWM执行和进程级失效停车 / Vision, strategy, GPIO/PWM execution and process-level fail-safe | 当前架构；GPIO映射待实物冻结 / Current architecture; physical mapping pending |
| 上一版本 / Previous version | Arduino UNO R3 | 不安装于当前车辆 / Not installed on the current vehicle | 0 | 上一版串口执行控制 / Previous serial execution control | 仅保留历史程序 / Historical code only |
| 驱动 / Drive | 电机驱动器 / Motor driver | AT8236 or DRV8701/MD02 Pro | 1 | 放大控制信号并驱动电机 / Amplify control signals and drive motor | 实物二选一 / Select from actual hardware |
| 驱动 / Drive | 带编码器接口电机 / Motor with encoder interface | 6–12 V, 12 CPR, 1:8.864, dual channel | 1 set | 当前只提供四轮动力 / Currently supplies four-wheel drive only | 反馈不使用 / Feedback not used |
| 转向 / Steering | 舵机 / Servo | 4.5–7 V, 10 kg·cm, 400–800 mA | 1 | 前轮转向 / Front-wheel steering | 规格确认，待实测 / Specification confirmed; measurement pending |
| 感知 / Perception | USB摄像头 / USB camera | GC0308/HBVCAM, 160°, distorted, 30 FPS colour, non-night-vision, 480p | 1 | 赛道和红绿障碍视觉 / Track and red-green obstacle vision | SKU确认，待实测 / SKU confirmed; measurement pending |
| 电源 / Power | 电池 / Battery | 团队早期实验使用11.1 V锂电 / Earlier team experiments used 11.1 V lithium | 1 | 整车能量 / Vehicle energy | 最终型号待核 / Final model pending |
| 电源 / Power | 稳压模块 / Regulators | 型号待确认 / Model pending | 一个或多个 / One or more | 稳定供电 / Regulated power | 待核 / Pending |
| 安全 / Safety | 总开关 / Main switch | 型号待确认 / Model pending | 1 | 一次动作上电 / Single-action power-on | 待核 / Pending |
| 安全 / Safety | 启动按钮 / Start button | 常开按钮接GND / Normally-open button to GND | 1 | 独立启动程序 / Independent program start | 程序支持，实物待装 / Software supported; hardware pending |
| 结构 / Structure | 紧固件与支架 / Fasteners and brackets | 建议M3，按实物确认 / M3 suggested; verify physically | 若干 / Several | 固定设备和线束 / Secure devices and wiring | 待核 / Pending |

当前BOM不包含前方或右侧超声波。底盘编码器接口不接线、不读取、不做闭环；相关程序只是历史示例。

The current BOM contains no front or right ultrasonic sensor. Chassis encoder interfaces are not wired, read or used in closed-loop control; related programs are historical examples only.

## 选型逻辑 / Selection Rationale

### 当前Orange Pi GPIO直控 / Current Orange Pi Direct GPIO Control

当前版本由Orange Pi同时完成视觉决策与GPIO/PWM执行。电机方向、启动按钮使用3.3 V GPIO，电机速度和舵机使用内核PWM。优点是减少一块控制器和串口链路；代价是Linux进程和GPIO输出属于同一故障域，必须使用上电默认停车、物理按钮、进程级250 ms看门狗、退出清零和实测最坏停车距离。实际GPIO line与PWM chip/channel必须从冻结镜像和实物排针确认。

The current version performs both vision decisions and GPIO/PWM execution on the Orange Pi. A 3.3 V GPIO controls motor direction and the physical start button, while kernel PWM controls motor speed and steering. This removes one controller and the serial link, but places Linux processing and actuator output in one failure domain. Stopped-by-default startup, a physical button, a 250 ms process-level watchdog, zero-on-exit and measured worst-case stopping distance are therefore required. Actual GPIO lines and PWM chip/channel values must be confirmed from the frozen image and physical header.

### 上一版Arduino UNO / Previous Arduino UNO Version

Arduino UNO串口执行程序属于上一版本，当前车辆不安装、不供电、不接线。程序保留用于说明迭代过程和两级控制方案的取舍，不能在当前接线图或比赛车辆配置中标为执行控制器。

The Arduino UNO serial executor belongs to the previous version and is not installed, powered or wired in the current vehicle. Its code remains as engineering-history evidence and to explain the trade-off of a two-controller architecture; it must not be presented as the current execution controller or wiring.

### ESP32

ESP32代码是团队早期自主实验版本，当前车辆不使用。若未来更换，必须关闭Wi-Fi和蓝牙，并重新验证接线和安全逻辑。

The ESP32 code is an earlier team-developed experimental version and is not used by the current vehicle. If adopted later, Wi-Fi and Bluetooth must be disabled and all wiring and safety logic revalidated.

### Orange Pi Zero 3W 4GB

团队购买的是带字母W的A733八核Zero 3W 4GB版本，不是H618四核Zero 3。它负责Linux、OpenCV、赛道与障碍识别、高层决策以及GPIO/PWM执行。比赛时关闭Wi-Fi 6和Bluetooth 5.4。独立供电按5 V/3 A设计。

The team purchased the A733 octa-core Zero 3W 4GB version with the letter W, not the H618 quad-core Zero 3. It runs Linux, OpenCV, track/obstacle recognition, high-level decisions and GPIO/PWM execution. Wi-Fi 6 and Bluetooth 5.4 must be disabled during competition. Use an independent 5 V/3 A supply.

### USB彩色摄像头 / USB Colour Camera

160°、30 FPS彩色SKU保留红绿信息，适合障碍分类。团队购买记录中的“1920×1080”与30万像素、480p相互矛盾，因此文档以SKU明确的480p为暂定值，并要求用UVC枚举确定实机模式。

The 160°, 30 FPS colour SKU preserves red-green information for obstacle classification. The team purchase record lists both “1920×1080” and conflicting 0.3-megapixel/480p information, so 480p is retained only as a provisional value until UVC enumeration establishes the actual mode.

### AT8236与DRV8701 / AT8236 and DRV8701

AT8236示例用双PWM控制，DRV8701/MD02 Pro示例使用PWM和DIR。程序必须分开维护，最终只有实车驱动器可标为比赛版本。

AT8236 examples use dual-PWM control, while DRV8701/MD02 Pro examples use PWM and DIR. Keep their programs separate; only the driver installed on the vehicle may be marked as the competition version.

## 待补证据 / Evidence Still Required

- 关键部件正反面和标签照片 / Front, rear and label photographs of key components.
- 购买链接或规格书存档 / Archived purchase links or datasheets.
- 实测质量、电压、典型和峰值电流 / Measured mass, voltage, typical current and peak current.
- 车上安装位置 / Installed location on the vehicle.
- 替代件和需要重新标定的参数 / Alternatives and parameters requiring recalibration.

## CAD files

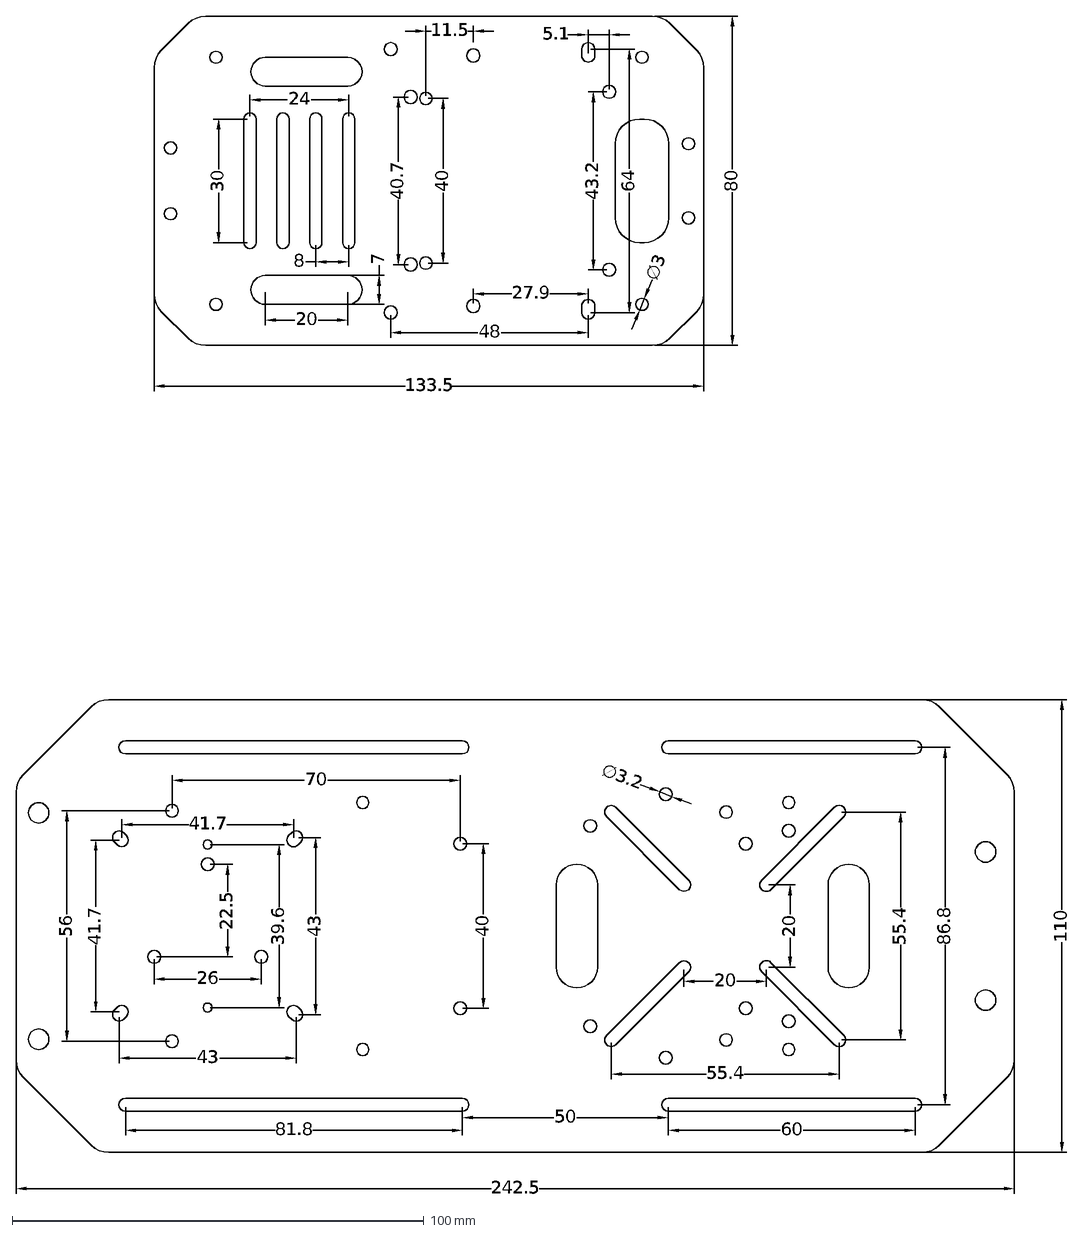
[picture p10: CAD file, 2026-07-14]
models模型/HSP94182层板.dxf
110
242.5
80
8
55.4
20
86.8
60
81.8
50
43
41.7
22.5
26
39.6
40
56
70
30
7
24
5.1
11.5
∅3
∅3.2
133.5
64
48
27.9
40.7
43.2

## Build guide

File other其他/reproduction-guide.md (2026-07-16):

# 完整复现指南 / Complete Reproduction Guide

> 目标：未参与开发的队员仅凭仓库，在不口头询问原开发者的情况下恢复当前纯视觉、Orange Pi GPIO/PWM直控车辆。 / Goal: a member who did not develop the system can restore the current vision-only, direct Orange Pi GPIO/PWM vehicle using only this repository and no verbal help.

## 1. 当前配置边界 / Current Configuration Boundary

- 安装：阿克曼四驱底盘、Orange Pi Zero 3W 4GB、USB彩色摄像头、PWM/DIR电机驱动器、转向舵机、物理启动/停止按钮和独立供电分支。 / Installed: four-wheel-drive Ackermann chassis, Orange Pi Zero 3W 4GB, USB colour camera, PWM/DIR motor driver, steering servo, physical start/stop button and separate power branches.
- 不安装：Arduino、超声波和编码器信号。 / Not installed: Arduino, ultrasonic sensors or encoder signals.
- 当前控制：Orange Pi直接输出GPIO/PWM；无板间串口。 / Current control: direct Orange Pi GPIO/PWM output; no inter-board serial link.
- 历史目录中的Arduino/ESP32程序只用于研发追溯。 / Arduino/ESP32 programs in historical folders are for development traceability only.

## 2. 所需工具 / Required Tools

- 带电流限制的台式电源或已核验电池、保险和总开关 / Current-limited bench supply or verified battery, fuse and main switch.
- 万用表、示波器或逻辑分析仪 / Multimeter, oscilloscope or logic analyser.
- 直尺、卡尺、电子秤和地面画圆工具 / Ruler, callipers, scale and ground-circle tools.
- Orange Pi系统镜像、读卡器、USB键盘/屏幕或有线调试方式 / Orange Pi image, card reader and local keyboard/display or wired debugging.
- Python 3、OpenCV、NumPy、python-periphery和libgpiod工具 / Python 3, OpenCV, NumPy, python-periphery and libgpiod tools.
- 摄像头标定板、稳定支架和充足光照 / Camera calibration board, rigid mount and suitable lighting.

## 3. 机械装配 / Mechanical Assembly

1. 依据 [`../models模型/README.md`](../models模型/README.md)核对轴距、轮距、轮径、转向连杆和传动。 / Use the mechanical guide to verify wheelbase, track, wheel diameter, steering links and drivetrain.
2. 固定Orange Pi和摄像头，确保视野无遮挡、线束不进入转向或传动机构。 / Mount the Orange Pi and camera; keep the view clear and wiring away from steering and drivetrain parts.
3. 固定电源、驱动器、舵机支路和总开关，重物尽量低且靠近车体中心。 / Secure the power system, driver, servo branch and main switch; keep heavy parts low and near the centre.
4. 在完整比赛配置下记录最终长、宽、高、质量、重心趋势和六视图。 / Record final dimensions, mass, centre-of-gravity trend and six views in complete competition configuration.

## 4. GPIO/PWM映射冻结 / GPIO/PWM Mapping Freeze

实际映射不能从名称猜测，必须在最终比赛镜像上完成：

Do not guess mappings from names; complete the following on the final competition image:

```bash
uname -a
cat /etc/os-release
gpiodetect
gpioinfo
ls -l /dev/gpiochip*
find /sys/class/pwm -maxdepth 3 -type f -o -type l
```

1. 在排针图、SoC手册、设备树和枚举输出之间建立物理针脚 → gpiochip/line、PWM chip/channel的对照表。 / Build a physical-header-to-gpiochip/line and PWM chip/channel table from the header map, SoC documentation, device tree and enumeration output.
2. 检查PWM通道没有被风扇、显示或其他overlay占用。 / Confirm PWM channels are not owned by a fan, display or another overlay.
3. 确认电机驱动器输入兼容3.3 V，物理按钮使用外部上拉，所有控制地相连。 / Confirm driver inputs accept 3.3 V, the physical button uses an external pull-up and all control grounds are common.
4. 把 [`../src源代码/gpio_config.example.json`](../src源代码/gpio_config.example.json) 复制为本地 `gpio_config.json`，填写映射但保持 `enabled=false`。 / Copy the example to local `gpio_config.json`, enter mappings but keep `enabled=false`.
5. 由程序和电子队员共同核对并签字，再允许启用。 / Programming and electronics members cross-check and sign before enabling.

## 5. 配电与接线 / Power Distribution and Wiring

按照 [`../schemes原理图/wiring.md`](../schemes原理图/wiring.md) 和 [`../schemes原理图/system-wiring.png`](../schemes原理图/system-wiring.png) 连接：

Wire according to the wiring guide and formal diagram:

1. 电池经保险和总开关进入配电。 / Battery enters distribution through a fuse and main switch.
2. 电机驱动器使用动力支路；Orange Pi使用独立稳压5 V/3 A支路；舵机使用独立4.5–7 V支路。 / Use a motor-power branch, an independent regulated 5 V/3 A Orange Pi branch and a separate 4.5–7 V servo branch.
3. USB摄像头直接接Orange Pi。 / Connect the USB camera directly to the Orange Pi.
4. Orange Pi的方向GPIO与电机PWM接驱动器，舵机PWM接舵机，按钮GPIO接常开按钮与外部上拉。 / Connect Orange Pi direction GPIO and motor PWM to the driver, steering PWM to the servo, and button GPIO to the normally-open button with external pull-up.
5. 控制共地；电机大电流回流短且与USB/信号线分开。 / Use a common control ground; keep high-current motor returns short and separated from USB/signal wiring.
6. 负载不得由Orange Pi排针供电。 / Do not power actuator loads from the Orange Pi header.

## 6. 软件恢复 / Software Restoration

```bash
cd src源代码
python3 -m pip install -r requirements.txt
python3 -m py_compile bev_road.py bev_segmentation.py orange_pi_gpio.py
cp gpio_config.example.json gpio_config.json
```

记录OS、内核、Python、OpenCV、NumPy和python-periphery版本，并保存 `gpio_config.json` 哈希但不要提交含本机映射的文件，除非团队决定公开最终映射。

Record OS, kernel, Python, OpenCV, NumPy and python-periphery versions, and save the `gpio_config.json` hash. Do not commit the machine-specific mapping unless the team decides to publish the final mapping.

先保持 `enabled=false`：

Keep `enabled=false` first:

```bash
python3 bev_segmentation.py --video-in 0 --mode cw --gpio-config gpio_config.json
```

确认界面为 `DRY_RUN`、默认速度0、视频丢失后目标归零。再用录像完成透视、HSV和方向策略调试。

Confirm `DRY_RUN`, zero default speed and zero target after video loss. Then tune perspective, HSV and direction strategy using recordings.

## 7. 首次硬件启用 / First Hardware Enable

1. 断开电机动力，启用配置，只测GPIO输入和PWM空载波形。 / Disconnect motor power, enable the configuration and test only GPIO input and unloaded PWM waveforms.
2. 测量电机PWM频率、舵机50 Hz及最小/中位/最大脉宽。 / Measure motor PWM frequency, steering 50 Hz and minimum/centre/maximum pulse widths.
3. 连接驱动器逻辑但保持动力断开，核实有效电平和方向符号。 / Connect driver logic with motor power still disconnected; verify active levels and direction sign.
4. 抬起驱动轮，使用限流电源和最低输出完成G-01至G-10。 / Lift the driven wheels and perform G-01 through G-10 using a current-limited supply and minimum output.
5. 特别测量250 ms看门狗、物理停止、摄像头断开、异常退出和方向变化前归零。 / Specifically measure the 250 ms watchdog, physical stop, camera loss, exception exit and zero-before-direction-change.
6. 只有程序、电子和教练共同签字后才进行地面低速测试。 / Begin low-speed ground testing only after programming, electronics and coach sign-off.

## 8. 标定与整车验收 / Calibration and Vehicle Acceptance

1. 标定摄像头内参与畸变、安装姿态、ROI和透视点。 / Calibrate camera intrinsics/distortion, mounting pose, ROI and perspective points.
2. 在多光照数据集上标定红绿HSV，报告precision、recall和F1。 / Tune red-green HSV on a multi-lighting dataset and report precision, recall and F1.
3. 标定舵机中位、左右安全脉宽、转向符号、最小转弯半径和速度档位。 / Calibrate steering centre, safe pulse limits, steering sign, minimum turning radius and speed levels.
4. 测量静态、视觉、电机启动和最大转向时的各支路电压电流。 / Measure branch voltage/current at idle, vision processing, motor start and maximum steering.
5. 完成顺/逆时针直线、弯道、障碍、完整回合、停车区、30分钟稳定性和最坏停车距离测试。 / Complete CW/CCW straight, turn, obstacle, full-lap, parking, 30-minute stability and worst-case stopping-distance tests.

## 9. 单板安全边界 / Single-board Safety Boundary

当前视觉与执行在同一Orange Pi。进程看门狗可覆盖控制循环停止，但不能保证覆盖Linux内核或PWM整体冻结。在可立即断电、抬轮和限流条件下完成故障注入，并根据结果决定是否加入独立硬件使能门、驱动器硬件使能失效保护或常闭急停。未完成前不得声称已覆盖所有处理器冻结故障。

Vision and execution share one Orange Pi. The process watchdog covers a stopped control loop but cannot guarantee stopping during a complete Linux-kernel or PWM freeze. Perform fault injection with immediate power removal, lifted wheels and current limiting, then decide on an independent hardware enable gate, driver-enable fail-safe or normally-closed emergency stop. Do not claim full processor-freeze coverage before this is complete.

## 10. 独立复现验收 / Independent Reproduction Acceptance

未参与编程的队员应仅依据仓库完成：定位文件、恢复镜像、枚举GPIO/PWM、核对映射、安装依赖、执行DRY_RUN、解释状态机、完成抬轮G-01至G-10、找到日志并指出上一版本与当前版本边界。记录总用时、卡住步骤和修改建议。只有不需要口头补充且所有关键映射有证据时，才能声明“完全可复现”。

A member who did not write the software must use only the repository to locate files, restore the image, enumerate GPIO/PWM, verify mapping, install dependencies, run DRY_RUN, explain the state machine, complete lifted-wheel G-01 through G-10, locate logs and identify the previous/current version boundary. Record total time, blocked steps and proposed edits. Claim “fully reproducible” only when no verbal additions are needed and every critical mapping has evidence.

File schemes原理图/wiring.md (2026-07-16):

# Orange Pi GPIO直控接线与供电 / Orange Pi Direct-GPIO Wiring and Power

**当前配置：** USB彩色摄像头是唯一环境传感器。Orange Pi Zero 3W在同一车载计算平台上完成视觉、策略以及GPIO/PWM执行，直接控制转向舵机和电机驱动器。当前车辆不安装Arduino，不连接超声波，也不读取编码器。

**Current configuration:** The USB colour camera is the only environmental sensor. The Orange Pi Zero 3W performs vision, strategy and GPIO/PWM execution on the same onboard computer and directly controls the steering servo and motor driver. The current vehicle has no Arduino, ultrasonic sensor or encoder feedback.

## 1. 当前信号接口 / Current Signal Interfaces

GPIO line编号、PWM chip/channel和物理排针编号取决于最终Linux镜像、设备树配置和实际选用排针。团队尚未提供这些实测映射，因此下表明确保留待填字段，不编造针脚号。

GPIO line numbers, PWM chip/channels and physical header pins depend on the final Linux image, device-tree configuration and selected header pins. The team has not yet supplied this measured mapping, so the table keeps explicit pending fields rather than inventing pin numbers.

| 功能 / Function | Orange Pi资源 / Resource | 外设端 / Device Side | 电气与状态要求 / Electrical and State Requirement |
|---|---|---|---|
| 电机速度 / Motor speed | PWM chip/channel：待实机枚举 / Pending enumeration | 电机驱动器PWM / Driver PWM | 3.3 V逻辑必须兼容；默认占空比0 / Verify 3.3 V logic; default duty 0 |
| 电机方向 / Motor direction | `/dev/gpiochipN` line：待实机枚举 / Pending enumeration | 电机驱动器DIR / Driver DIR | 3.3 V输出；换向前PWM归零 / 3.3 V output; zero PWM before reversing |
| 转向舵机 / Steering servo | PWM chip/channel：待实机枚举 / Pending enumeration | 舵机信号 / Servo signal | 50 Hz；脉宽限位待架空标定 / 50 Hz; pulse limits require lifted calibration |
| 物理启动/停止 / Physical start/stop | `/dev/gpiochipN` line：待实机枚举 / Pending enumeration | 常开按钮到GND / Normally-open button to GND | 3.3 V外部上拉；按下为低 / External 3.3 V pull-up; active low |
| 摄像头 / Camera | USB/UVC | USB彩色摄像头 / USB colour camera | 固定插头并保存枚举 / Secure connector and save enumeration |
| 共地 / Common ground | Orange Pi GND | 驱动器、舵机电源和按钮GND / Driver, servo supply and button ground | 信号参考必须共地 / Common signal reference required |

实际映射填写到 [`gpio_config.json`](../src源代码/gpio_config.example.json) 的本地副本。仓库中的示例以 `enabled=false` 和 `-1` 占位，防止未核对针脚时意外输出。

Enter the verified mapping in a local copy named `gpio_config.json`, based on [`gpio_config.example.json`](../src源代码/gpio_config.example.json). The repository example uses `enabled=false` and `-1` placeholders to prevent output before pin verification.

## 2. 3.3 V逻辑与执行器隔离 / 3.3 V Logic and Actuator Isolation

Orange Pi GPIO只提供控制信号，不能直接为舵机、电机或驱动器功率级供电。必须逐项确认驱动器PWM/DIR输入和舵机信号端能可靠识别3.3 V；若阈值不兼容，应使用合适的缓冲或电平转换。任何外设都不得把5 V或更高电压反灌到Orange Pi GPIO。

Orange Pi GPIO supplies control signals only and must never power the servo, motor or driver power stage. Verify that driver PWM/DIR inputs and the servo signal input reliably accept 3.3 V. Use a suitable buffer or level shifter if thresholds are incompatible. No peripheral may feed 5 V or a higher voltage back into an Orange Pi GPIO.

- GPIO与PWM信号串联适当保护电阻，具体值根据边沿和驱动器输入实测 / Use suitable series protection resistors on GPIO/PWM signals, selected from measured edge and input behaviour.
- 启动按钮使用外部上拉到3.3 V，不上拉到5 V / Pull the start button up to 3.3 V externally, never to 5 V.
- 动力地回路短而粗，避免大电流经过Orange Pi细地线 / Keep power returns short and thick; do not route load current through a thin Orange Pi ground lead.
- 上电前用万用表检查每个信号对地电压 / Measure every signal-to-ground voltage before power-up.

## 3. 配电结构 / Power Distribution

| 支路 / Branch | 供电 / Supply | 负载 / Load | 要求 / Requirement |
|---|---|---|---|
| 主动力 / Main power | 最终电池，型号待核 / Final battery, model pending | 电机驱动器功率端 / Motor-driver power stage | 保险、总开关、线径按峰值电流选择 / Fuse, switch and wire gauge from measured peak |
| 计算与视觉 / Compute and vision | 独立稳压5 V/3 A / Independent regulated 5 V/3 A | Orange Pi + USB摄像头 / Orange Pi + USB camera | 记录启动、视觉和满负载最低电压 / Record minimum voltage at boot, vision and full load |
| 舵机 / Servo | 4.5-7 V合适稳压 / Suitable 4.5-7 V regulated branch | 转向舵机 / Steering servo | 不从Orange Pi排针取电；记录堵转峰值 / Do not power from Orange Pi header; record stall peak |
| 控制信号 / Control signals | Orange Pi 3.3 V逻辑 / Orange Pi 3.3 V logic | PWM、DIR和按钮 / PWM, DIR and button | 仅信号电流 / Signal current only |

总开关必须一次动作切断车辆驱动能量。Orange Pi正常关机流程与紧急断电是两件事；比赛安全不能依赖桌面操作或网络命令。

The main switch must remove vehicle drive energy in one action. Normal Orange Pi shutdown and emergency power removal are separate functions; competition safety must not depend on desktop interaction or a network command.

## 4. 正式系统图 / Formal System Diagram

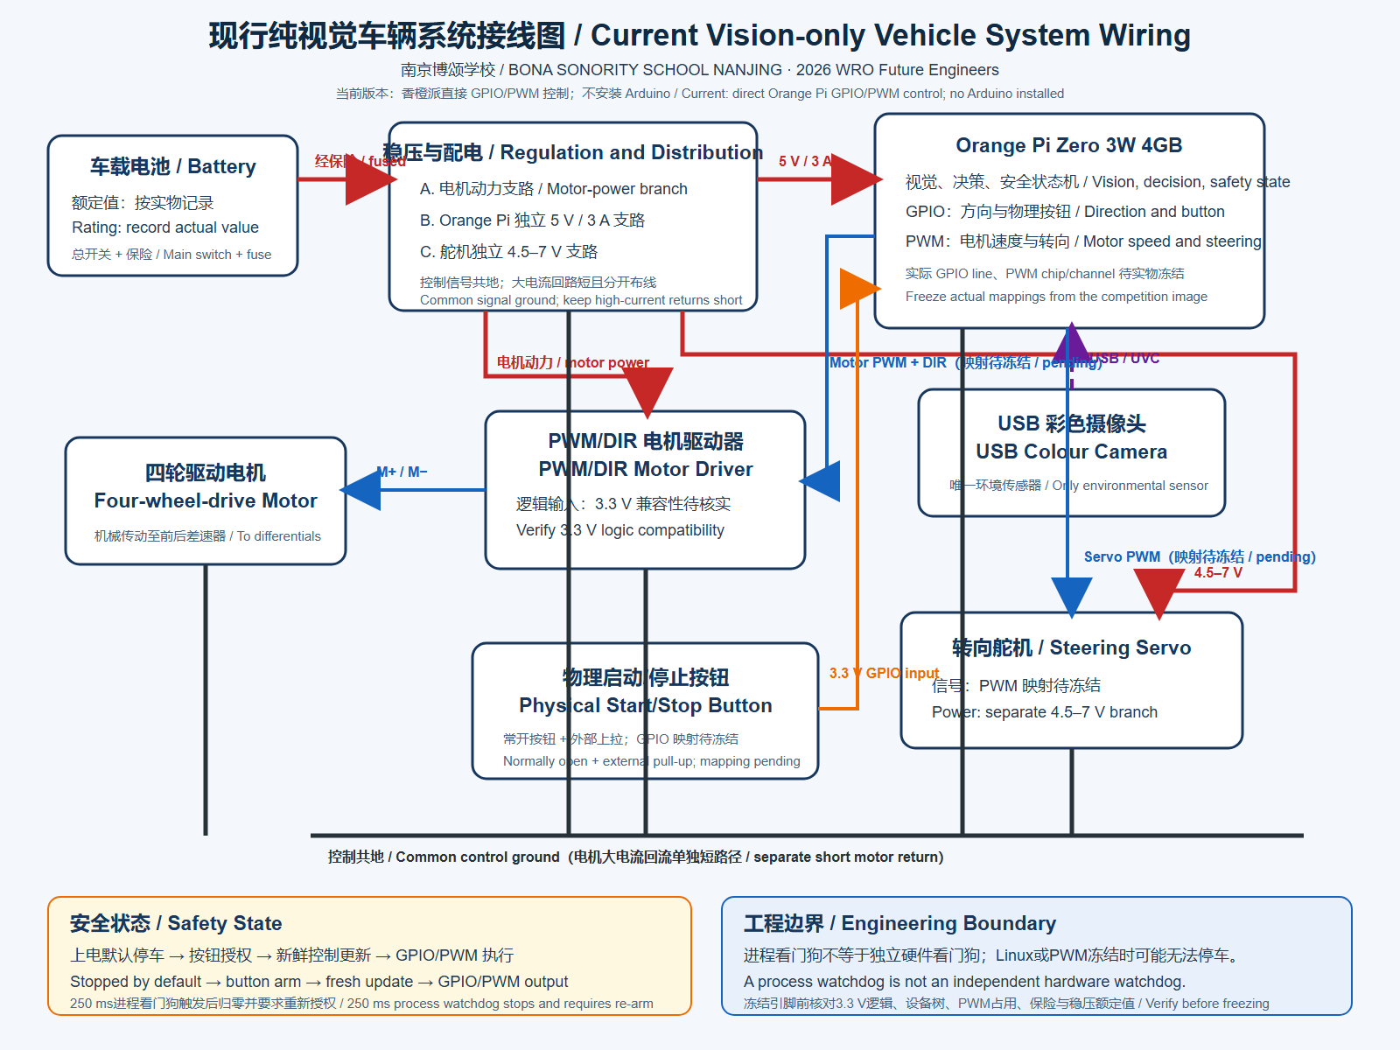
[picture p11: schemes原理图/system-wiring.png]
Orange Pi GPIO直控系统接线图 / Orange Pi direct-GPIO system wiring


- [PNG接线图 / PNG wiring diagram](system-wiring.png)
- [SVG源文件 / SVG source](system-wiring.svg)

```mermaid
flowchart LR
  CAM["USB彩色摄像头 / USB colour camera"] --> OPI["Orange Pi Zero 3W / 视觉+决策+GPIO执行 / vision+decision+GPIO execution"]
  BTN["物理启动/停止按钮 / Physical start-stop button"] -->|"3.3 V GPIO输入 / input"| OPI
  OPI -->|"PWM：映射待核 / mapping pending"| SERVO["转向舵机 / Steering servo"]
  OPI -->|"PWM + DIR：映射待核 / mapping pending"| DRIVER["电机驱动器 / Motor driver"]
  DRIVER --> MOTOR["四轮机械驱动 / Mechanical 4WD"]
  BAT["车载电池 / Vehicle battery"] --> DIST["保险、总开关与配电 / Fuse, main switch and distribution"]
  DIST --> DRIVER
  DIST --> REG5["5 V/3 A稳压 / regulator"]
  REG5 --> OPI
  DIST --> REGS["舵机稳压 / Servo regulator"]
  REGS --> SERVO
```

## 5. GPIO输出与安全状态 / GPIO Output and Safety States

当前程序是 [`orange_pi_gpio.py`](../src源代码/orange_pi_gpio.py)，由 [`bev_segmentation.py`](../src源代码/bev_segmentation.py)直接调用。状态如下：

The current output module is [`orange_pi_gpio.py`](../src源代码/orange_pi_gpio.py), called directly by [`bev_segmentation.py`](../src源代码/bev_segmentation.py). Its states are:

| 状态 / State | 进入条件 / Entry | 输出 / Output | 恢复 / Recovery |
|---|---|---|---|
| `DRY_RUN` | 配置不存在或 `enabled=false` / Missing config or disabled | 不打开GPIO/PWM，仅运行视觉 / No GPIO/PWM access; vision only | 核对映射后启用 / Enable after mapping verification |
| `WAIT_START` | 硬件初始化、人工停车 / Hardware initialisation or manual stop | 电机0、舵机中位 / Motor zero, steering centre | 物理按钮 / Physical button |
| `GPIO_DRIVE` | 物理按钮按下 / Physical button press | 执行最新受限视觉目标 / Apply latest limited vision target | 持续控制更新 / Continued control updates |
| `CONTROL_FAILSAFE` | 超过250 ms无控制更新 / No update for over 250 ms | 电机0、舵机中位 / Motor zero, steering centre | 必须再次按物理按钮 / Physical re-arm required |
| `CLOSED` | 程序正常或异常退出 / Normal or abnormal program exit | PWM禁用、资源关闭 / PWM disabled and resources closed | 重新启动完整程序 / Restart full program |

GPIO直控取消了串口和Arduino，但也取消了独立微控制器故障隔离。进程级看门狗线程不能替代硬件看门狗：如果Linux内核、PWM子系统或整个Orange Pi冻结，Python线程也可能无法执行停车。因此必须实测故障边界，并在最终安全评估中明确是否需要独立硬件使能门或电源级失效保护。

Direct GPIO control removes the serial link and Arduino, but also removes independent microcontroller fault isolation. A process-level watchdog thread is not a hardware watchdog: if the Linux kernel, PWM subsystem or entire Orange Pi freezes, Python may not execute the stop action. Test this boundary and explicitly decide whether an independent hardware enable gate or power-stage fail-safe is required.

## 6. 实机枚举与冻结 / Hardware Enumeration and Freeze

在最终镜像上保存以下输出，并把结果写入本页和证据登记表：

Save the following output on the final image and record the results here and in the evidence register:

```bash
gpiodetect
gpioinfo
ls -l /dev/gpiochip*
ls -l /sys/class/pwm
find /sys/class/pwm -maxdepth 2 -type f -print
```

还要保存物理排针照片，并建立“物理针脚 - SoC名称 - gpiochip/line或PWM chip/channel - 程序字段”四列映射。任何镜像或设备树变更后必须重新枚举。

Also preserve a physical-header photograph and a four-column mapping from physical pin to SoC name, gpiochip/line or PWM chip/channel, and configuration field. Re-enumerate after every image or device-tree change.

## 7. 上电检查 / Power-On Checklist

1. 驱动轮架空，总开关断开，确认接线和极性 / Lift drive wheels, keep the main switch off and verify wiring and polarity.
2. 不连接舵机和驱动器输入，先枚举GPIO/PWM并用示波器检查3.3 V、频率和默认低输出 / With actuators disconnected, enumerate GPIO/PWM and verify 3.3 V, frequency and safe defaults on an oscilloscope.
3. 复制示例配置，填写实测映射，保持 `enabled=false` 完成软件自检 / Copy the example, enter measured mappings and keep `enabled=false` for software self-test.
4. 接入驱动器但断开电机动力，确认方向、PWM和按钮逻辑 / Connect driver control with motor power removed; verify direction, PWM and button logic.
5. 接入舵机并架空标定中位、左右极限和峰值电流 / Connect the servo and calibrate centre, limits and peak current with wheels lifted.
6. 最后接电机动力，从低占空比测试并完成G-01至G-10 / Connect motor power last, begin at low duty and complete G-01 through G-10.

## 8. 上一版本边界 / Previous-Version Boundary

`VisionSerialExecutor.ino`、UNO D2/D6/D7/D8接线以及 `steer,speed` 串口协议属于上一版本。它们仅作为迭代记录保留，不得用于当前装车图、当前BOM或当前比赛配置说明。

`VisionSerialExecutor.ino`, UNO D2/D6/D7/D8 wiring and the `steer,speed` serial protocol belong to the previous version. They remain only as iteration history and must not appear in the current vehicle diagram, current BOM or current competition configuration.

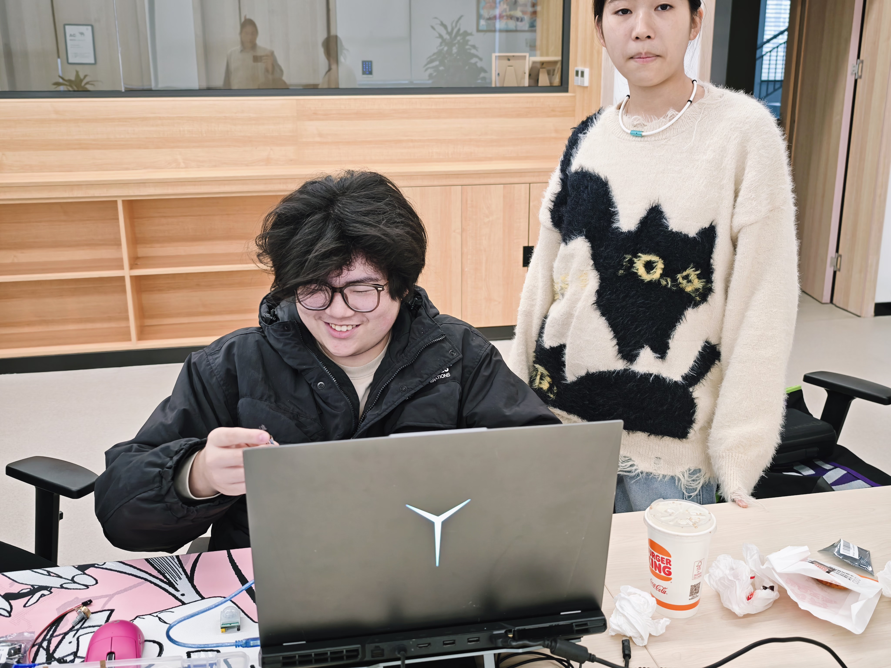
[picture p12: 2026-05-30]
t-photos团队照片/making-process-03-hardware-debug.jpg

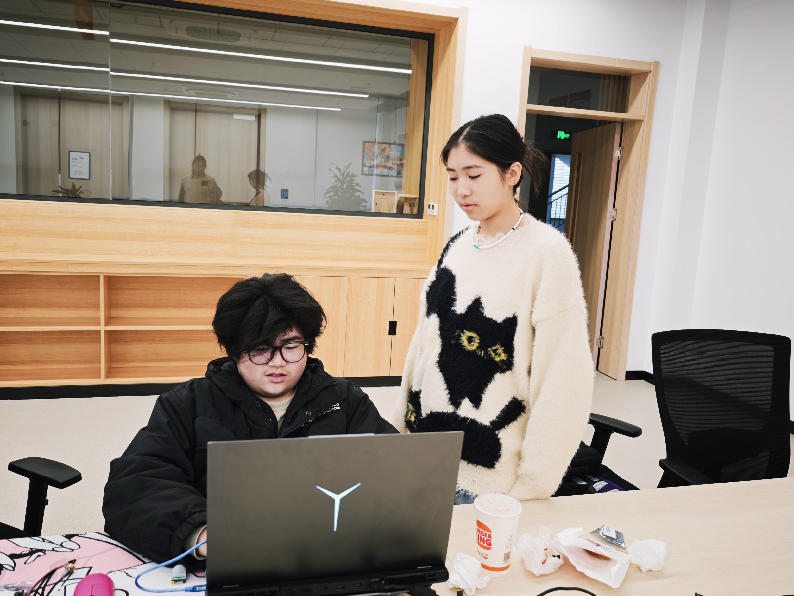
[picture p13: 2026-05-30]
t-photos团队照片/making-process-02-software-discussion.jpg

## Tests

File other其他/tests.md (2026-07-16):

# 测试流程与结果记录 / Test Procedure and Results

> 范围：纯视觉识别、Orange Pi GPIO/PWM执行、故障停车和整车性能；当前车辆不包含Arduino、串口、超声波或编码器。 / Scope: vision-only perception, Orange Pi GPIO/PWM execution, fault stopping and full-vehicle performance; the current vehicle has no Arduino, serial link, ultrasonic sensor or encoder.

所有测试必须填写日期、软件提交号、系统镜像、内核、配置文件哈希、执行人、环境、至少五次重复值和原始证据路径。“通过”不能代替实测数值。

Every test must record date, software commit, system image, kernel, configuration hash, operator, environment, at least five repeated values and raw-evidence paths. “Pass” cannot replace measurements.

## 1. 测试安全前提 / Test Safety Preconditions

1. 先断开电机动力，核对3.3 V逻辑、共地、极性和电源分支。 / Disconnect motor power first; verify 3.3 V logic, common ground, polarity and power branches.
2. 首次输出测试抬起驱动轮，并使车辆不会碰到人员或物品。 / Lift the driven wheels for initial output tests and restrain the vehicle.
3. 旁站人员掌握总电源并能立即断电。 / A spotter controls the main power and can disconnect it immediately.
4. 初次运行保持 `enabled=false`；冻结映射和波形后才启用。 / Keep `enabled=false` initially; enable only after mapping and waveform sign-off.
5. 每次变更引脚、设备树、驱动器、舵机或电源后重新执行G-01至G-10。 / Repeat G-01 through G-10 after any pin, device-tree, driver, servo or power change.

## 2. GPIO/PWM安全验收 / GPIO/PWM Safety Acceptance

| ID | 操作 / Action | 预期结果 / Expected Result | 实际结果 / Actual Result | 证据 / Evidence | 结论 / Result |
|---|---|---|---|---|---|
| G-01 | `enabled=false`运行程序 / Run with `enabled=false` | `DRY_RUN`；不打开GPIO/PWM，不运动 / `DRY_RUN`; no GPIO/PWM opened and no motion | 待测 / Pending | 日志 + 枚举前后对比 / Log + enumeration diff | 待测 / Pending |
| G-02 | `enabled=true`后上电，不按按钮 / Power up without pressing the button | `WAIT_START`；电机0、舵机中位 / `WAIT_START`; zero motor, centred steering | 待测 / Pending | 波形 + 视频 / Waveform + video | 待测 / Pending |
| G-03 | 按钮授权但不给新控制更新 / Arm without a fresh control update | 不运动，250 ms后失效 / No motion; fail-safe after 250 ms | 待测 / Pending | 日志 + 波形 / Log + waveform | 待测 / Pending |
| G-04 | 输入 `-100, 0, +100`及越界值 / Apply boundary and out-of-range values | 限幅正确；脉宽/占空比符合配置 / Values bounded; pulse/duty match configuration | 待测 / Pending | 示波器/逻辑分析仪 / Oscilloscope/logic analyser | 待测 / Pending |
| G-05 | 运动时停止控制更新 / Stop updates while moving | 最后更新后约250 ms电机PWM归零 / Motor PWM zero about 250 ms after last update | 待测 / Pending | 五次延迟值 / Five latency values | 待测 / Pending |
| G-06 | G-05后恢复目标但不按按钮 / Resume targets after G-05 without button | 不自动恢复，保持停车 / No automatic recovery; remains stopped | 待测 / Pending | 日志 + 视频 / Log + video | 待测 / Pending |
| G-07 | 运动中按物理按钮 / Press physical button while moving | 立即停车并回到 `WAIT_START` / Immediate stop and `WAIT_START` | 待测 / Pending | 延迟 + 视频 / Latency + video | 待测 / Pending |
| G-08 | 拔摄像头、冻结帧或停止视觉 / Disconnect camera, freeze frames or stop vision | 请求速度0，输出层停车 / Zero request and stopped output | 待测 / Pending | 日志 + 波形 / Log + waveform | 待测 / Pending |
| G-09 | 注入异常、Ctrl+C和正常退出 / Inject exception, Ctrl+C and normal exit | PWM归零/禁用，舵机中位，资源释放 / PWM zero/disabled, steering centred, resources released | 待测 / Pending | 三类日志 + 波形 / Three logs + waveforms | 待测 / Pending |
| G-10 | 五次上电和五次正反向切换 / Five power cycles and five direction changes | 不出现上电运动；方向改变前PWM先归零 / No power-on motion; PWM zero before direction change | 待测 / Pending | 连续视频 + 波形 / Continuous video + waveform | 待测 / Pending |

### G-05原始延迟 / G-05 Raw Latencies

| 重复 / Trial | 最后更新时刻 / Last Update | PWM归零时刻 / PWM Zero | 延迟ms / Latency ms | 判定 / Result |
|---|---:|---:|---:|---|
| 1 | 待测 / Pending | 待测 / Pending | 待测 / Pending | 待测 / Pending |
| 2 | 待测 / Pending | 待测 / Pending | 待测 / Pending | 待测 / Pending |
| 3 | 待测 / Pending | 待测 / Pending | 待测 / Pending | 待测 / Pending |
| 4 | 待测 / Pending | 待测 / Pending | 待测 / Pending | 待测 / Pending |
| 5 | 待测 / Pending | 待测 / Pending | 待测 / Pending | 待测 / Pending |

## 3. 摄像头与视觉 / Camera and Vision

| ID | 测试 / Test | 方法 / Method | 指标 / Metric | 实际 / Actual |
|---|---|---|---|---|
| V-01 | 内参与畸变 / Intrinsics and distortion | 棋盘格覆盖画面各区域 / Checkerboard across the frame | 重投影误差px / Reprojection error px | 待测 / Pending |
| V-02 | 透视与ROI / Perspective and ROI | 已知地面点和赛道边界 / Known ground points and track borders | 边界误差px / Border error px | 待测 / Pending |
| V-03 | 红绿识别 / Red-green detection | 多距离、多角度、多光照标注集 / Labelled set across distance, angle and lighting | Precision, recall, F1 | 待测 / Pending |
| V-04 | 方向与道路 / Direction and road | 顺/逆时针录像及实车 / CW/CCW recordings and vehicle | 正确率 / Accuracy | 待测 / Pending |
| V-05 | 帧率与延迟 / FPS and latency | 30分钟连续运行 / 30-minute continuous run | mean/P95 FPS and latency | 待测 / Pending |
| V-06 | 低置信度策略 / Low-confidence policy | 反光、阴影、遮挡和模糊 / Reflection, shadow, occlusion and blur | 减速/停车正确率 / Correct slow/stop rate | 待测 / Pending |

红绿测试集必须包含原始图、标注、参数、运行脚本和结果CSV。禁止只展示成功样例。

The red-green dataset must include raw images, labels, parameters, run script and result CSV. Showing only successful examples is not acceptable.

## 4. 机械、电气与整车 / Mechanical, Electrical and Full Vehicle

| ID | 项目 / Item | 条件 / Condition | 记录 / Record |
|---|---|---|---|
| H-01 | 最终长宽高、质量 / Final size and mass | 完整比赛配置 / Complete competition configuration | 待测 / Pending |
| H-02 | 舵机中位与机械极限 / Steering centre and limits | 抬轮、低速、保留机械余量 / Lifted wheels, low speed, mechanical margin | 待测 / Pending |
| H-03 | 最小转弯半径 / Minimum turning radius | 顺/逆时针各5次 / Five CW and five CCW runs | 待测 / Pending |
| E-01 | 静态与视觉运行电流 / Idle and vision current | 电池、5 V和舵机支路 / Battery, 5 V and servo branches | 待测 / Pending |
| E-02 | 电机启动压降 / Motor-start voltage sag | 最低与最高测试速度 / Lowest and highest test speed | 待测 / Pending |
| E-03 | 舵机堵转风险 / Servo stall risk | 安全限位附近短时测试 / Brief test near safe limits | 待测 / Pending |
| R-01 | 直线、转弯与障碍 / Straight, turn and obstacle | 两种赛道方向各5回合 / Five laps in both directions | 成功率、时间、碰撞 / Success, time, contacts |
| R-02 | 停车区与圈数 / Parking and lap count | 完整规则流程 / Complete rule flow | 待实现/待测 / Pending implementation/test |
| R-03 | 30分钟稳定性 / 30-minute stability | 比赛速度、摄像头与日志全开 / Competition speed, camera and logging | 重启、掉帧、温度 / Restarts, drops, temperature |

## 5. 单板故障边界测试 / Single-board Fault-Boundary Test

进程看门狗不能证明Linux或PWM整体冻结时一定停车。完成常规测试后，应在抬轮和可立即断电条件下，分别注入：视觉线程停止、主循环停止、看门狗线程停止、用户态进程挂起、GPIO/PWM设备异常以及受控的系统失联。记录哪些故障仍能让输出归零，哪些不能，并据此关闭FMEA中的独立硬件失效保护决策。

A process watchdog does not prove stopping during a complete Linux or PWM freeze. After normal tests, with wheels lifted and immediate power removal available, separately inject a stopped vision thread, stopped main loop, stopped watchdog thread, suspended user process, GPIO/PWM device error and controlled system unresponsiveness. Record which faults still zero outputs and which do not, then use the results to close the independent-hardware-fail-safe decision in the FMEA.

## 6. 测试签字 / Test Sign-off

| 角色 / Role | 姓名 / Name | 日期 / Date | 结论 / Decision | 签字 / Signature |
|---|---|---|---|---|
| 程序 / Programming | 陆昭颖 / Lu Zhaoying | 待填 / Pending | 待填 / Pending | 待填 / Pending |
| 结构 / Mechanical | 张隽泽 / Zhang Junze | 待填 / Pending | 待填 / Pending | 待填 / Pending |
| 电子 / Electronics | 黄鸣博 / Huang Mingbo | 待填 / Pending | 待填 / Pending | 待填 / Pending |
| 教练 / Coach | 薛源 / Xue Yuan | 待填 / Pending | 待填 / Pending | 待填 / Pending |

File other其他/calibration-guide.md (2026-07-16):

# 标定与参数调优手册 / Calibration and Parameter-Tuning Guide

**当前范围：** 只标定舵机、摄像头、视觉参数和开环速度命令；不标定超声波或编码器。

**Current scope:** Calibrate only the servo, camera, vision parameters and open-loop speed commands; ultrasonic and encoder calibration is not used.

## 总原则 / General Principle

一次只改变一个参数，并记录提交号、电池电压、场地、轮胎和结果。顺序为机械与舵机→摄像头→视觉→速度映射→完整回合。

Change one parameter at a time and record commit, battery voltage, field, tyres and result. Follow mechanical/servo → camera → vision → speed mapping → full laps.

## 1. 舵机 / Servo

1. 抬轮并断开电机动力 / Lift wheels and disconnect motor power.
2. 输出90°并调整舵臂、拉杆到直行 / Output 90° and adjust horn/links for straight wheels.
3. 每2°寻找无机械顶死的左右极限 / Step by 2° to find non-binding limits.
4. 内缩3°–5°作为软件余量 / Move inward by 3°–5° for software margin.
5. 低速直行2 m微调中位 / Fine-tune centre over a 2 m low-speed run.
6. 保存 `SERVO_RIGHT/CENTER/LEFT` 并拍照 / Save values and photographs.

## 2. 当前不适用 / Not Applicable to Current Configuration

编码器接口不接线，不做速度闭环；前方和右侧超声波不安装。底盘规格中的CPR、减速比和团队早期超声波参数仅作历史参考。

Encoder interfaces are not connected and no speed loop is used; front and right ultrasonic sensors are not installed. CPR and gear ratio from the chassis specifications, together with the team's earlier ultrasonic parameters, are historical references only.

## 3. 视觉速度映射 / Vision Speed Mapping

架空确认方向，再用固定距离记录多个 `speed` 命令的平均速度和停车距离；在不同电量重复，设置最大速度、弯道限速、障碍减速和失效停车。当前是目标量到PWM的开环映射，不称为速度PI。

Confirm direction with wheels lifted, then record average speed and stopping distance for several `speed` commands over a fixed distance. Repeat at different battery levels and set maximum speed, turn limit, obstacle slowdown and failure stop. This is open-loop target-to-PWM mapping, not speed PI.

## 4. 视觉转向与恢复 / Vision Steering and Recovery

低速确认道路和信标转向符号；从小权重和小最大转向开始。蛇形时降低权重/限幅或增加平滑。测试直道、弯道、边缘、阴影、反光、双颜色和短时丢失。参数以完整回合成功率和零碰撞为准。

At low speed, confirm road and beacon steering signs; begin with small weights and steering limits. If oscillation occurs, reduce weights/limits or increase smoothing. Test straights, turns, image edges, shadows, reflections, both colours and temporary loss. Select parameters by full-lap success and zero collisions.

顺逆时针参数可分别保存。遮挡或目标丢失必须停车，不得盲行。

CW and CCW parameters may be stored separately. Occlusion or target loss must cause a stop, never blind travel.

## 5. 摄像头 / Camera

1. 固定最终位置、焦距和支架 / Fix final position, focus and mount.
2. 在中央、四角和不同距离采集15–20张棋盘格 / Capture 15–20 checkerboards at centre, corners and distances.
3. 保存内参、畸变系数和分辨率 / Save intrinsics, distortion and resolution.
4. 检查去畸变直线并避免过度裁剪 / Check straight lines and avoid excessive cropping.
5. 采集红、绿、黑墙、地垫、阴影和反光 / Capture red, green, black wall, mat, shadow and reflection samples.
6. 在HSV或Lab设阈值并记录光照范围 / Set HSV or Lab thresholds and record lighting ranges.
7. 用独立数据计算误检、漏检和延迟 / Measure false positives, misses and latency on independent data.
8. 核对曝光和白平衡锁定 / Check exposure and white-balance locking.

160°镜头边缘畸变明显，必须去畸变或使用像素到视角查找表。

The 160° lens has strong edge distortion; use undistortion or a pixel-to-angle lookup table.

## 标定记录 / Calibration Record

| 日期 / Date | 项目 / Item | 修改前 / Before | 修改后 / After | 条件 / Conditions | 结果 / Result | 提交 / Commit |
|---|---|---|---|---|---|---|
| 待填 / TBD | 舵机中位 / Servo centre | 90° | | 抬轮+2 m / Lifted + 2 m | | |
| 待填 / TBD | 摄像头角度 / Camera angle | 待测 / TBD | | 固定支架 / Fixed mount | | |
| 待填 / TBD | 速度映射 / Speed mapping | 默认 / Default | | 固定距离 / Fixed distance | | |
| 待填 / TBD | 道路/信标权重 / Road/beacon weights | 默认 / Default | | 赛道+障碍 / Track + obstacle | | |

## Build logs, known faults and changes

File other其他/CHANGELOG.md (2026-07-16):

# 版本与工程迭代日志 / Version and Engineering Changelog

## V1.0 历史巡墙基线 / Historical Wall-Following Baseline

- Arduino UNO、双超声波、舵机、PWM/DIR、30 cm右墙P控制和串口日志 / Arduino UNO, dual ultrasonic, servo, PWM/DIR, 30 cm right-wall P control and serial logging.
- 局限：无启动、颜色、速度闭环、停车区或滤波 / Limits: no start state, colour, speed loop, parking zone or filtering.

## V1.1–V2.0 早期计划 / Early Plans

- 曾计划超声波滤波、编码器PID和完整状态机 / Previously planned ultrasonic filtering, encoder PID and a full state machine.
- 当时路线改为Orange Pi视觉+Arduino安全执行，并计划有线协议、绕障、圈数和停车；该架构后来被单板GPIO直控替代 / The route at that time changed to Orange Pi vision + Arduino safety execution with wired protocol, avoidance, lap count and parking; it was later replaced by single-board GPIO control.

## 2026-07-15 视觉计算平台 / Vision Compute Platform

- 确认Zero 3W 4GB/A733并区别Zero 3/H618 / Confirmed Zero 3W 4GB/A733, distinct from Zero 3/H618.
- 记录CPU、NPU、接口、5 V/3 A、散热、验收、BOM、接线、风险和复现 / Documented CPU, NPU, interfaces, power, cooling, acceptance, BOM, wiring, risk and reproduction.
- 实机枚举、协议和稳定性待验 / Hardware enumeration, protocol and stability pending.

## 2026-07-16 视觉源码与安全 / Vision Source and Safety

- 加入两份Python程序、依赖和串口示例 / Added two Python programs, dependencies and serial example.
- 默认速度改0，修正阈值和制动，丢源/退出发送停止 / Set default speed to zero, corrected thresholds/braking and stop on source loss/exit.
- 首页整合视频、照片、状态和索引 / Integrated video, photos, status and index on landing page.

## 2026-07-16 照片和赛事资料 / Photos and Competition Material

- 统一命名11张制作过程照片 / Renamed 11 process photographs consistently.
- 加入正式团队照、北京冠军照和比赛车辆照 / Added official team, Beijing championship and competition-vehicle photos.
- 趣味团队照和六视图待补 / Informal team photo and six views pending.

## 2026-07-16 视觉唯一感知 / Vision-Only Perception

- 确认只使用USB摄像头和Orange Pi，不使用超声波/编码器 / Confirmed USB camera and Orange Pi only, with no ultrasonic/encoder use.
- 当时信号链为摄像头→Orange Pi→有线串口→Arduino→执行器，现仅作上一版本记录 / The chain at that stage was camera→Orange Pi→wired serial→Arduino→actuators and is now a previous-version record only.
- 历史传感器程序统一标记为参考 / Marked historical sensor programs as references.
- 压缩视频为H.264 1080p/30 FPS、106.8秒、87.07 MiB并进入Git / Added compressed H.264 1080p/30 FPS, 106.8 s, 87.07 MiB video to Git.

## 2026-07-16 团队资料 / Team Profile

- 加入队旗、校名、成员、教练和职责 / Added flag, school name, members, coach and roles.
- 加入陆昭颖两张照片和张隽泽照片 / Added two Lu Zhaoying portraits and one Zhang Junze portrait.
- 加入黄鸣博正式成员照并补齐三名队员个人照片 / Added Huang Mingbo's formal portrait and completed the three-member portrait set.
- 首页、团队页和照片索引互链 / Linked landing page, team profile and photo index.

## 2026-07-16 全仓库中英对照 / Repository-Wide Bilingual Documentation

- 首页及全部Markdown文档改为中文后紧跟英文 / Converted the landing page and all Markdown documents to Chinese followed directly by English.
- 标题、正文、表格、检查项和图片说明均双语化 / Made headings, prose, tables, checklists and image captions bilingual.

## 2026-07-16 规则评分审计与工程归档 / Rule-Rubric Audit and Engineering Archive

- 逐页核对2026规则第8页和附录C五维30分技术文档量表 / Audited rule page 8 and the Appendix C five-dimension, 30-point documentation rubric page by page.
- 新增五维评分证据地图、缺失证据登记、提交计划和双语工程日志PDF / Added a five-dimension evidence map, missing-evidence register, commit plan and bilingual engineering-log PDF.
- 新增正式PNG/SVG接线图和可重复生成PDF的脚本 / Added formal PNG/SVG wiring diagrams and a reproducible PDF build script.
- 新增当时的视觉串口执行程序：D8物理启动、严格解析、输出限幅、250 ms看门狗和故障后重新启动；现标记为上一版本 / Added the then-current vision serial executor with D8 physical start, strict parsing, output limits, a 250 ms watchdog and post-fault re-arm; now marked as the previous version.
- 使用Arduino AVR Boards `1.8.8`和Servo `1.3.0`完成UNO目标编译：5544 bytes程序空间、277 bytes全局变量 / Completed an UNO-target build with Arduino AVR Boards `1.8.8` and Servo `1.3.0`: 5,544 bytes of program storage and 277 bytes of global-variable memory.
- 明确区分当前ASCII协议与尚未实现的序号/时间戳/CRC增强协议 / Clearly separated the current ASCII protocol from the unimplemented sequence/timestamp/CRC hardened protocol.
- 本轮只更新工作区，未暂存、提交或推送 / Updated the working tree only; nothing was staged, committed or pushed.

## 2026-07-16 Orange Pi GPIO/PWM直控 / Direct Orange Pi GPIO/PWM Control

- 删除当前车辆的具体车型编号，仅保留经实物确认的阿克曼四驱机械特征与尺寸 / Removed the current vehicle's specific model identifier while retaining verified Ackermann four-wheel-drive features and dimensions.
- 现行链路改为摄像头→Orange Pi视觉/决策/安全状态→GPIO/PWM→舵机与电机驱动器，不安装Arduino，不使用板间串口 / Changed the current chain to camera→Orange Pi vision/decision/safety state→GPIO/PWM→servo and motor driver, with no Arduino or inter-board serial link.
- 新增 `orange_pi_gpio.py` 和默认 `enabled=false`、映射为 `-1` 的 `gpio_config.example.json`，防止未知引脚误动作 / Added `orange_pi_gpio.py` and a `gpio_config.example.json` with `enabled=false` and `-1` mappings to prevent movement from unknown pins.
- 视觉程序改为同进程调用GPIO输出层，加入物理按钮、限幅、方向切换前归零、250 ms控制更新看门狗、异常/退出清理 / Updated vision to call the GPIO output layer in-process, adding a physical button, limits, zero-before-direction-change, a 250 ms control-update watchdog and exception/exit cleanup.
- 重写现行接线图、软件架构、测试G-01至G-10、复现指南、FMEA、评分证据和工程日志，Arduino内容仅保留为明确的上一版本历史 / Rebuilt the current wiring, software architecture, G-01 through G-10 tests, reproduction guide, FMEA, scoring evidence and engineering log; Arduino remains only as clearly labelled previous-version history.
- 明确真实GPIO line与PWM chip/channel必须由冻结镜像、设备树、排针和枚举结果确认，未填写推测值 / Required real GPIO lines and PWM chip/channels to be confirmed from the frozen image, device tree, header and enumeration; no guessed values were entered.
- 明确进程看门狗不能保证覆盖Linux/PWM整体冻结，增加故障注入和独立硬件使能保护决策项 / Documented that a process watchdog cannot guarantee coverage of a complete Linux/PWM freeze and added fault-injection and independent-hardware-enable decision items.
- 本轮只更新工作区，未暂存、提交或推送 / Updated the working tree only; nothing was staged, committed or pushed.

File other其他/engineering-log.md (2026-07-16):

# 工程研发日志 / Engineering Log

本日志只记录已有成果和明确计划，不为未知日期虚构事件。 / This log records existing results and explicit plans only; unknown dates are never invented.

## 阶段1：建立仓库 / Stage 1: Repository Setup

采用官方模板建立照片、视频、原理图、代码、模型和技术材料目录，并重写首页导航与缺口清单。 / Adopted the official template for photos, video, schematics, code, models and technical materials, then rebuilt landing-page navigation and the gap list.

## 阶段2：历史巡墙基线 / Stage 2: Historical Wall-Following Baseline

早期Arduino使用前/右超声波、舵机和PWM/DIR，实现30 cm右墙P控制。它缺少启动状态、速度闭环、转弯和异常停车，当前不使用。 / The early Arduino used front/right ultrasonic sensors, servo and PWM/DIR for 30 cm right-wall P control. It lacked start state, speed loop, turning and fault stop and is not currently used.

## 阶段3–4：底盘资料与参考程序 / Stages 3–4: Chassis Data and Reference Programs

确认阿克曼四驱结构及AT8236、DRV8701和ESP32示例，提取尺寸和编码器参考，并按驱动器分开代码。新增PI/PD、状态机和安全结构的参考程序，但当前只作历史资料。 / Confirmed the four-wheel-drive Ackermann structure and AT8236, DRV8701 and ESP32 examples, extracted dimensional/encoder references and separated code by driver. Added reference PI/PD, state-machine and safety structures, retained only as history.

## 阶段5：Orange Pi视觉平台 / Stage 5: Orange Pi Vision Platform

确认Orange Pi Zero 3W 4GB/A733。当时建立“Orange Pi视觉决策+Arduino执行安全”试验架构，记录USB摄像头、有线串口、独立5 V/3 A、散热和无线关闭。该双控制器方案后来被阶段13的Orange Pi GPIO/PWM直控方案替代。传统CPU/OpenCV仍为基线，NPU尚未验证。 / Confirmed Orange Pi Zero 3W 4GB/A733. At that stage, the team established an experimental “Orange Pi vision decisions + Arduino execution safety” architecture and documented USB camera, wired serial, independent 5 V/3 A, cooling and wireless shutdown. Stage 13 later replaced that two-controller design with direct Orange Pi GPIO/PWM control. CPU/OpenCV remains the baseline; NPU is unverified.

## 阶段6：视觉原型 / Stage 6: Vision Prototype

加入 `bev_road.py` 和 `bev_segmentation.py`，完成语法检查及默认停车、阈值、制动和退出停车修正。当时原型仍包含串口输出；现行阶段13已改为同进程GPIO/PWM输出。透视、HSV和实车验证仍待完成。 / Added both Python programs, completed syntax checks and corrected default stop, thresholds, braking and exit stop. The prototype still contained serial output at that stage; current Stage 13 replaces it with in-process GPIO/PWM output. Perspective, HSV and vehicle validation remain pending.

## 阶段7–8：照片与赛事证据 / Stages 7–8: Photos and Competition Evidence

整理11张制作过程照片，并加入三名成员照、正式团队照、北京站冠军照和比赛车辆照片。趣味团队照和车辆六视图待补。 / Indexed 11 process photos and added all three member portraits, the official team photograph, Beijing championship photograph and competition-vehicle photograph. The informal team photograph and six vehicle views are pending.

## 阶段9：视觉唯一感知 / Stage 9: Vision-Only Perception

确认只使用USB摄像头进行环境感知，不安装超声波、不读取编码器。当时版本仍由Arduino执行视觉目标；现行阶段13已取消Arduino。 / Confirmed the USB camera as the only environmental sensor, with no ultrasonic sensors or encoder readings. At that stage the Arduino still executed vision targets; current Stage 13 removes the Arduino.

## 阶段10：团队资料 / Stage 10: Team Profile

加入队旗、双语校名、三名队员、教练、职责和成员照片，并从首页直接链接。 / Added flag, bilingual school name, three members, coach, roles and portraits, linked from the landing page.

## 阶段11：上一版规则复核与串口安全闭环 / Stage 11: Previous-Version Rule Audit and Serial Safety Closure

上一版方案依据2026规则附录C和技术文档评分表重新核对五个评分维度，建立评分证据地图、实测/照片登记表和提交拆分建议。审计发现当时视觉程序已发送 `steer,speed`，但仓库没有匹配的UNO执行端，而且旧程序引脚与候选接线不一致。为消除当时的复现断点，新增PWM/DIR串口执行候选：D2舵机、D6 PWM、D7 DIR、D8物理按钮，上电默认停车，畸形命令不刷新看门狗，250 ms无合法命令进入故障，恢复必须重新按键并收到新命令。该候选已被阶段13的Orange Pi GPIO/PWM直控替代，现仅作版本演进证据。

The previous-version design was re-audited against 2026 Appendix C and the engineering-documentation score sheet, producing a scoring-evidence map, a measurement/photograph register and a commit-grouping recommendation. The audit found that the vision program transmitted `steer,speed` but lacked a matching UNO executor, while historical sketch pins contradicted candidate wiring. A D2/D6/D7/D8 PWM/DIR serial executor was added to close that reproduction break. Stage 13 superseded it with direct Orange Pi GPIO/PWM control, so it now serves only as version-evolution evidence.

## 阶段12：上一版UNO目标编译验证 / Stage 12: Previous-Version UNO-Target Build Verification

使用Arduino AVR Boards `1.8.8`和标准Servo库 `1.3.0`编译上一版 `VisionSerialExecutor.ino`，UNO目标编译通过，占用5544 bytes程序空间（17%）和277 bytes全局变量（13%）。这只消除了该历史版本的语法、目标平台和依赖风险；当时计划的实物烧录与U系列测试已由阶段13的G-01至G-10取代。

The previous-version `VisionSerialExecutor.ino` was compiled using Arduino AVR Boards `1.8.8` and the standard Servo library `1.3.0`. The UNO-target build passed, using 5,544 bytes of program storage (17%) and 277 bytes of global-variable memory (13%). This closes only that historical version's syntax, target-platform and dependency risks; Stage 13 replaces its planned upload and U-series tests with G-01 through G-10.

该结果只证明上一版程序可以编译。由于当前车辆不安装Arduino，上一版的烧录和U系列测试不再属于现行验收计划。 / This result proves only that the previous-version program builds. Because the current vehicle has no Arduino, previous-version upload and U-series tests are no longer part of current acceptance.

## 阶段13：Orange Pi GPIO/PWM直控 / Stage 13: Direct Orange Pi GPIO/PWM Control

根据最终装车方案，控制链改为“USB摄像头 → Orange Pi视觉与决策 → 同板GPIO/PWM → 舵机和电机驱动器”，并明确当前不安装Arduino、不使用板间串口。新增 `orange_pi_gpio.py` 与默认禁用的 `gpio_config.example.json`，将物理按钮、电机方向、电机PWM、舵机PWM、输出限幅、方向变化前归零、250 ms控制更新看门狗和退出清理集中在一个模块。`bev_segmentation.py`改为直接调用该模块，Python核心文件已通过语法检查。

The final vehicle architecture changes the chain to “USB camera → Orange Pi vision and decisions → same-board GPIO/PWM → steering servo and motor driver”, explicitly with no Arduino or inter-board serial link. `orange_pi_gpio.py` and a disabled-by-default `gpio_config.example.json` were added, centralising the physical button, motor direction, motor PWM, steering PWM, output limits, zero-before-direction-change, 250 ms control-update watchdog and exit cleanup. `bev_segmentation.py` now calls this module directly, and the core Python files pass syntax checks.

为避免虚构，真实GPIO line与PWM chip/channel保持 `-1`，必须依据冻结比赛镜像、设备树、实物排针和枚举结果确认。新接线图、BOM、软件架构、测试G-01至G-10、复现指南、FMEA和评分证据同步到单板直控。文档同时明确残余风险：进程看门狗不能保证Linux内核或PWM整体冻结时停车，必须故障注入并评估独立硬件使能保护。

To avoid invented data, real GPIO lines and PWM chip/channels remain `-1` until confirmed from the frozen competition image, device tree, physical header and enumeration. The wiring diagram, BOM, software architecture, G-01 through G-10 tests, reproduction guide, FMEA and scoring map are synchronised to single-board direct control. The documentation also records the residual risk: a process watchdog cannot guarantee stopping during a complete Linux-kernel or PWM freeze, so fault injection and an independent hardware enable must be assessed.

## 下一轮实验 / Next Experiments

| 优先级 / Priority | 实验 / Experiment | 目标与证据 / Goal and Evidence |
|---:|---|---|
| 1 | GPIO/PWM资源冻结 / GPIO/PWM resource freeze | 排针、gpiochip/line、PWM chip/channel、overlay、照片和签字 / Header, line/channel, overlay, photographs and sign-off |
| 2 | 舵机极限 / Servo limits | 无顶死，角度+视频 / No stall, angles+video |
| 3 | 摄像头标定 / Camera calibration | 内参、畸变、ROI、安装角 / Intrinsics, distortion, ROI, angle |
| 4 | 电源负载 / Power load | 无复位，电压电流 / No reset, voltage/current |
| 5 | 速度映射 / Speed mapping | 多电量可预测 / Predictable across battery levels |
| 6 | 视觉转向 / Vision steering | 连续10回合无碰撞 / Ten collision-free laps |
| 7 | CW/CCW弯道 / CW/CCW turns | 四角稳定 / Stable at four corners |
| 8 | 系统验收 / System acceptance | 内存、摄像头、GPIO/PWM枚举和G-01至G-10 / Memory, camera, GPIO/PWM enumeration and G-01 through G-10 |
| 9 | 延迟温度 / Latency and temperature | 30分钟日志 / 30-minute log |
| 10 | 故障安全 / Fault safety | 遮挡、摄像头断开、进程停止及Linux/PWM冻结边界 / Obstruction, camera loss, process stop and Linux/PWM freeze boundary |

## 单次日志模板 / Single-Test Template

- 日期与实验 / Date and experiment:
- 参与人员 / Participants:
- Git提交 / Commit:
- 硬件与电池 / Hardware and battery:
- 场地与光照 / Field and lighting:
- 目标与参数 / Goal and parameters:
- 过程与数据 / Procedure and data:
- 结果：成功/部分成功/失败 / Result: success/partial/failure:
- 问题与下一步 / Issues and next step:

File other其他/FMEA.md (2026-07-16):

# 故障模式与风险分析 / Failure Mode and Effects Analysis (FMEA)

摄像头是唯一环境感知源，且当前视觉与GPIO/PWM执行位于同一Orange Pi，因此摄像头/视觉失效、控制更新停止、GPIO/PWM错误和整板冻结是最高优先级风险。

The camera is the only environmental sensor, and vision and GPIO/PWM execution share one Orange Pi. Camera/vision loss, stopped control updates, GPIO/PWM errors and complete-board freezes are therefore highest-priority risks.

严重度S、发生度O、可探测度D均为1–5，`RPN=S×O×D`。以下为设计初评，必须用实测发生率与可探测性更新。 / Severity S, occurrence O and detectability D use 1–5 scales, with `RPN=S×O×D`. These are design-stage estimates and must be updated with measured occurrence and detectability.

| 故障 / Failure | 影响 / Effect | 原因 / Cause | S | O | D | RPN | 现有控制 / Current Controls | 关闭措施 / Closure Action |
|---|---|---|---:|---:|---:|---:|---|---|
| 上电运动 / Motion at power-up | 人身、损坏或违规 / Injury, damage or violation | 输出默认值错误 / Wrong output defaults | 5 | 2 | 2 | 20 | `enabled=false`模板、`WAIT_START`、电机0 / Disabled template, `WAIT_START`, zero motor | G-01/G-02五次上电 / Five G-01/G-02 cycles |
| GPIO/PWM映射错误 / Wrong GPIO/PWM mapping | 误动作、短路或无控制 / Unintended motion, short or no control | 编号体系/设备树混淆 / Numbering or device-tree confusion | 5 | 3 | 4 | 60 | 所有模板映射为 `-1`，非法配置拒绝启用 / Template mappings `-1`; invalid config rejected | 排针/设备树/枚举三方核对并签字 / Three-way mapping check and sign-off |
| 3.3 V逻辑不兼容 / Incompatible 3.3 V logic | 不动作或损坏GPIO / No action or GPIO damage | 驱动器阈值未知 / Unknown driver thresholds | 5 | 2 | 4 | 接线前核验，必要时电平转换 / Verify first; level shift if needed | 数据与示波器实测 / Datasheet and scope measurement |
| 舵机顶死 / Servo stall | 过流或拉杆损坏 / Overcurrent or link damage | 脉宽限位错误 / Wrong pulse limits | 4 | 3 | 2 | 脉宽限幅、上电回中 / Pulse limits, centre at power-up | H-02机械极限与温升 / H-02 limits and temperature |
| 电机启动压降 / Motor-start sag | 重启、USB丢失或失控 / Reset, USB loss or loss of control | 稳压余量/线损 / Regulator margin or cable loss | 5 | 3 | 3 | 分支供电、保险、共地 / Separate branches, fuse, common ground | E-01/E-02峰值与最低电压 / Peak current and minimum voltage |
| 电机方向带载切换 / Direction change under torque | 驱动冲击或损坏 / Driver shock or damage | DIR改变时PWM非零 / Nonzero PWM during DIR change | 5 | 2 | 3 | 代码先归零PWM / Code zeroes PWM first | G-10波形验证 / G-10 waveform verification |
| 转向符号接反 / Reversed steering sign | 撞墙 / Wall impact | 安装/坐标约定错误 / Installation or coordinate error | 5 | 2 | 2 | DRY_RUN、抬轮与低速检查 / DRY_RUN, lifted and low-speed checks | 双向五次转弯 / Five turns each direction |
| 线束卷入或松脱 / Entangled or loose wiring | 机械损坏、信号丢失 / Mechanical damage or signal loss | 固定不足 / Poor securing | 5 | 2 | 3 | 扎带、应力释放、全行程观察 / Ties, strain relief, full-travel inspection | 六视图与赛前检查 / Six views and pre-run checks |
| 电量下降 / Battery depletion | 速度/转向变化或重启 / Motion change or reset | 无在线电量闭环 / No closed-loop battery monitoring | 4 | 4 | 3 | 限速、赛前电压和多电量测试 / Speed limits, pre-run voltage, multi-level tests | 建立可用电压窗口 / Define operating voltage window |
| 无线未关闭 / Wireless enabled | 规则违规或干扰 / Rule violation or interference | 默认服务 / Default services | 5 | 2 | 3 | 30 | `rfkill`、`ip link`、离线启动 / Radio checks and offline boot | 赛前截图与检查表 / Pre-run evidence and checklist |
| 广角畸变 / Wide-angle distortion | 位置误差 / Position error | 160°镜头 / Lens | 4 | 4 | 3 | 48 | 内参标定、去畸变、ROI / Calibration, undistortion, ROI | V-01/V-02误差数据 / Error data |
| 红绿误判 / Colour error | 绕行方向错误 / Wrong avoidance side | 光照、反光或遮挡 / Lighting, reflection or occlusion | 5 | 3 | 3 | 45 | 多光照数据、置信度门槛、减速 / Multi-light data, confidence gate, slowdown | V-03/V-06指标 / Metrics |
| USB断开或丢帧 / USB loss or frame drop | 感知失效 / Perception loss | 松线、欠压或负载 / Loose cable, undervoltage or load | 5 | 3 | 3 | 45 | 帧读取失败请求速度0 / Frame-read failure requests zero | G-08 + V-05连续测试 / G-08 + continuous test |
| 画面冻结 / Frozen image | 旧目标持续 / Stale target persists | 采集阻塞 / Capture stall | 5 | 2 | 4 | 40 | 单调时间、控制更新看门狗 / Monotonic time, control-update watchdog | 重复帧检测与G-08 / Duplicate-frame detection and G-08 |
| 主控制循环停止 / Main control loop stops | 旧输出持续 / Stale output persists | 死锁、异常或资源耗尽 / Deadlock, exception or exhaustion | 5 | 2 | 3 | 30 | 独立进程线程250 ms看门狗 / Separate process thread, 250 ms watchdog | G-05/G-09及30分钟压力 / G-05/G-09 and stress test |
| 看门狗线程停止 / Watchdog thread stops | 无软件失效停车 / No software fail-safe | 同进程故障 / Same-process fault | 5 | 2 | 5 | 50 | 当前仅可由故障注入发现 / Currently detectable only by injection | 评估独立硬件使能 / Evaluate independent hardware enable |
| Linux/PWM/整板冻结 / Linux, PWM or board freeze | PWM可能保持最后值 / PWM may hold last value | 内核、驱动、供电或硬件故障 / Kernel, driver, power or hardware fault | 5 | 2 | 5 | 50 | 总开关与人工旁站 / Main switch and spotter | 故障注入；决定硬件看门狗/EN门/常闭急停 / Inject faults; decide hardware watchdog, EN gate or NC stop |
| Orange Pi启动失败 / Orange Pi boot failure | 无控制 / No control | 存储损坏或欠压 / Storage failure or undervoltage | 5 | 2 | 2 | 20 | 默认无PWM、镜像备份、冷启动自检 / No default PWM, image backup, cold-boot check | 五次离线冷启动 / Five offline cold boots |
| 过热 / Overheating | 延迟、掉帧或重启 / Latency, drops or reset | 散热不足 / Poor cooling | 4 | 3 | 3 | 36 | 温度日志与30分钟测试 / Temperature log and 30-minute test | 固定散热方案与阈值 / Freeze cooling and thresholds |

## 高优先级关闭顺序 / High-Priority Closure Order

1. 冻结并签署真实GPIO/PWM映射和3.3 V接口兼容。 / Freeze and sign real GPIO/PWM mapping and 3.3 V compatibility.
2. 完成G-01至G-10，保留PWM、DIR和按钮波形。 / Complete G-01 through G-10 and retain PWM, DIR and button waveforms.
3. 注入摄像头丢失、画面冻结、主循环停止、进程挂起和PWM设备异常。 / Inject camera loss, frozen frames, stopped main loop, process suspension and PWM-device faults.
4. 依据Linux/PWM冻结结果决定并实现独立硬件失效保护。 / Decide and implement an independent hardware fail-safe from Linux/PWM-freeze results.
5. 完成电源、温度、30分钟稳定性、最坏停车距离和完整回合测试。 / Complete power, thermal, 30-minute stability, worst-case stopping distance and full-lap tests.

风险只有在“措施已实现 + 原始证据可追溯 + 团队签字”后才能从待关闭改为已关闭。 / A risk can be marked closed only after the control is implemented, raw evidence is traceable and the team signs it off.

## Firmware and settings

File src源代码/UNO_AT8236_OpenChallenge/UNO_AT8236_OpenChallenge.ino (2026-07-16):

/*
 * 2026 WRO Future Engineers - Open Challenge baseline
 * Hardware: Arduino UNO + AT8236 + four-wheel-drive Ackermann chassis (previous experiment)
 *
 * Functions:
 * - independent start button; the vehicle remains stopped after power-on
 * - Hall encoder speed PI control
 * - right-wall PD steering
 * - front-corner state machine and emergency stop
 * - serial telemetry for reproducible tuning
 *
 * IMPORTANT: verify every pin and physical constant on the actual vehicle.
 */
#include <Servo.h>

// ---------- Pin assignment: AT8236 uses two PWM inputs ----------
const byte PIN_ENCODER_A = 2;  // yellow, interrupt pin
const byte PIN_ENCODER_B = 4;  // white
const byte PIN_MOTOR_A = 5;
const byte PIN_MOTOR_B = 6;
const byte PIN_US_FRONT_TRIG = 7;
const byte PIN_US_FRONT_ECHO = 8;
const byte PIN_SERVO = 9;
const byte PIN_US_RIGHT_TRIG = 10;
const byte PIN_US_RIGHT_ECHO = 11;
const byte PIN_START = 12;     // button to GND, INPUT_PULLUP
const byte PIN_LED = 13;

// ---------- Chassis specification parameters; verify on the team vehicle ----------
const float ENCODER_CPR = 12.0f;
const float GEAR_RATIO = 8.864f;
const float WHEEL_DIAMETER_M = 0.047f;

// Servo calibration. The team's early test range is about 55..115 degrees.
const int SERVO_RIGHT = 55;
const int SERVO_CENTER = 90;
const int SERVO_LEFT = 115;

// ---------- Control parameters: tune from tests ----------
const float TARGET_SPEED_MPS = 0.35f;
const float SPEED_KP = 260.0f;
const float SPEED_KI = 110.0f;
const int PWM_MIN_MOVING = 45;
const int PWM_LIMIT = 150;       // conservative first-test limit

const float TARGET_RIGHT_CM = 30.0f;
const float WALL_KP = 1.8f;
const float WALL_KD = 3.0f;
const int MAX_STEER_COMMAND = 80;

const float FRONT_EMERGENCY_CM = 14.0f;
const float FRONT_TURN_CM = 38.0f;
const unsigned long TURN_TIME_MS = 720;
const unsigned long SENSOR_TIMEOUT_US = 25000;
const unsigned long CONTROL_PERIOD_MS = 50;

enum RobotState { WAIT_START, FOLLOW_WALL, TURN_LEFT, EMERGENCY_STOP };
RobotState state = WAIT_START;
Servo steering;
volatile long encoderTicks = 0;

float measuredSpeed = 0.0f;
float speedIntegral = 0.0f;
float previousWallError = 0.0f;
float filteredFront = 999.0f;
float filteredRight = 999.0f;
unsigned long lastControlMs = 0;
unsigned long stateStartMs = 0;

void encoderISR() {
  encoderTicks += (digitalRead(PIN_ENCODER_B) == LOW) ? 1 : -1;
}

float readDistanceCm(byte trig, byte echo) {
  digitalWrite(trig, LOW);
  delayMicroseconds(2);
  digitalWrite(trig, HIGH);
  delayMicroseconds(10);
  digitalWrite(trig, LOW);
  unsigned long duration = pulseIn(echo, HIGH, SENSOR_TIMEOUT_US);
  if (duration == 0) return 999.0f;
  float cm = duration * 0.0343f * 0.5f;
  if (cm < 2.0f || cm > 300.0f) return 999.0f;
  return cm;
}

float lowPass(float previous, float sample) {
  if (sample >= 900.0f) return sample;
  if (previous >= 900.0f) return sample;
  return 0.65f * previous + 0.35f * sample;
}

void setMotorPwm(int pwm) {
  pwm = constrain(pwm, -PWM_LIMIT, PWM_LIMIT);
  if (pwm > 0) {
    analogWrite(PIN_MOTOR_A, pwm);
    digitalWrite(PIN_MOTOR_B, LOW);
  } else if (pwm < 0) {
    digitalWrite(PIN_MOTOR_A, LOW);
    analogWrite(PIN_MOTOR_B, -pwm);
  } else {
    // The team's AT8236 experiment uses both HIGH as braking/stop.
    digitalWrite(PIN_MOTOR_A, HIGH);
    digitalWrite(PIN_MOTOR_B, HIGH);
  }
}

void setSteering(int command) {
  command = constrain(command, -100, 100);
  int angle;
  if (command < 0) {
    angle = map(command, -100, 0, SERVO_LEFT, SERVO_CENTER);
  } else {
    angle = map(command, 0, 100, SERVO_CENTER, SERVO_RIGHT);
  }
  steering.write(constrain(angle, SERVO_RIGHT, SERVO_LEFT));
}

void stopSafely() {
  setMotorPwm(0);
  setSteering(0);
  speedIntegral = 0.0f;
}

bool startButtonPressed() {
  static bool stable = HIGH;
  static bool rawPrevious = HIGH;
  static unsigned long changedAt = 0;
  bool raw = digitalRead(PIN_START);
  if (raw != rawPrevious) {
    changedAt = millis();
    rawPrevious = raw;
  }
  if (millis() - changedAt > 25 && raw != stable) {
    stable = raw;
    return stable == LOW;
  }
  return false;
}

void updateMeasuredSpeed(float dt) {
  noInterrupts();
  long ticks = encoderTicks;
  encoderTicks = 0;
  interrupts();
  float revolutions = ticks / (ENCODER_CPR * GEAR_RATIO);
  measuredSpeed = fabs(revolutions * PI * WHEEL_DIAMETER_M / dt);
}

int speedController(float target, float dt) {
  float error = target - measuredSpeed;
  speedIntegral += error * dt;
  speedIntegral = constrain(speedIntegral, -0.7f, 0.7f);
  int pwm = (int)(SPEED_KP * error + SPEED_KI * speedIntegral);
  if (target > 0.01f && pwm > 0 && pwm < PWM_MIN_MOVING) pwm = PWM_MIN_MOVING;
  return constrain(pwm, 0, PWM_LIMIT);
}

int wallController(float rightCm, float dt) {
  if (rightCm >= 900.0f) {
    previousWallError = 0.0f;
    return 0;  // degraded mode: straight until a valid reading returns
  }
  float error = rightCm - TARGET_RIGHT_CM;
  float derivative = (error - previousWallError) / dt;
  previousWallError = error;
  int command = (int)(WALL_KP * error + WALL_KD * derivative);
  return constrain(command, -MAX_STEER_COMMAND, MAX_STEER_COMMAND);
}

void setup() {
  Serial.begin(115200);
  pinMode(PIN_ENCODER_A, INPUT_PULLUP);
  pinMode(PIN_ENCODER_B, INPUT_PULLUP);
  pinMode(PIN_MOTOR_A, OUTPUT);
  pinMode(PIN_MOTOR_B, OUTPUT);
  pinMode(PIN_US_FRONT_TRIG, OUTPUT);
  pinMode(PIN_US_FRONT_ECHO, INPUT);
  pinMode(PIN_US_RIGHT_TRIG, OUTPUT);
  pinMode(PIN_US_RIGHT_ECHO, INPUT);
  pinMode(PIN_START, INPUT_PULLUP);
  pinMode(PIN_LED, OUTPUT);
  steering.attach(PIN_SERVO);
  attachInterrupt(digitalPinToInterrupt(PIN_ENCODER_A), encoderISR, RISING);
  stopSafely();
  lastControlMs = millis();
  Serial.println(F("WRO UNO+AT8236 ready; press the start button."));
}

void loop() {
  if (startButtonPressed()) {
    if (state == WAIT_START || state == EMERGENCY_STOP) {
      state = FOLLOW_WALL;
      stateStartMs = millis();
      speedIntegral = 0.0f;
    } else {
      state = EMERGENCY_STOP;  // same button can stop during testing
    }
  }

  unsigned long now = millis();
  if (now - lastControlMs < CONTROL_PERIOD_MS) return;
  float dt = (now - lastControlMs) / 1000.0f;
  lastControlMs = now;

  updateMeasuredSpeed(dt);
  filteredFront = lowPass(filteredFront, readDistanceCm(PIN_US_FRONT_TRIG, PIN_US_FRONT_ECHO));
  delayMicroseconds(1500); // reduce ultrasonic cross-talk
  filteredRight = lowPass(filteredRight, readDistanceCm(PIN_US_RIGHT_TRIG, PIN_US_RIGHT_ECHO));

  if (state != WAIT_START && filteredFront < FRONT_EMERGENCY_CM) {
    state = EMERGENCY_STOP;
  }

  switch (state) {
    case WAIT_START:
      stopSafely();
      break;
    case FOLLOW_WALL:
      if (filteredFront < FRONT_TURN_CM) {
        state = TURN_LEFT;
        stateStartMs = now;
      } else {
        setSteering(wallController(filteredRight, dt));
        setMotorPwm(speedController(TARGET_SPEED_MPS, dt));
      }
      break;
    case TURN_LEFT:
      setSteering(-85);
      setMotorPwm(speedController(TARGET_SPEED_MPS * 0.70f, dt));
      if (now - stateStartMs >= TURN_TIME_MS && filteredFront > FRONT_TURN_CM + 8.0f) {
        state = FOLLOW_WALL;
        previousWallError = 0.0f;
      }
      break;
    case EMERGENCY_STOP:
      stopSafely();
      break;
  }

  digitalWrite(PIN_LED, state == FOLLOW_WALL || state == TURN_LEFT);
  Serial.print((int)state); Serial.print(',');
  Serial.print(filteredFront, 1); Serial.print(',');
  Serial.print(filteredRight, 1); Serial.print(',');
  Serial.println(measuredSpeed, 3);
}

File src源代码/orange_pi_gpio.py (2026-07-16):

"""Orange Pi GPIO/PWM vehicle output with stopped-by-default safety.

香橙派GPIO/PWM整车输出层，默认停车并要求物理按钮启动。

The implementation uses Linux GPIO character devices and kernel PWM through
python-periphery. GPIO line numbers and PWM chip/channel numbers are deliberately
not hard-coded because they depend on the frozen Orange Pi image, device-tree
overlay and chosen header pins.

本程序使用python-periphery访问Linux GPIO字符设备和内核PWM。GPIO line编号、PWM
chip/channel与镜像、设备树和实际排针选择有关，因此仓库不编造固定编号。
"""

from __future__ import annotations

import json
import threading
import time
from dataclasses import dataclass
from enum import Enum
from pathlib import Path
from typing import Any, Optional


class OutputState(str, Enum):
    DRY_RUN = "DRY_RUN"
    WAIT_START = "WAIT_START"
    GPIO_DRIVE = "GPIO_DRIVE"
    CONTROL_FAILSAFE = "CONTROL_FAILSAFE"
    CLOSED = "CLOSED"


class GpioConfigurationError(RuntimeError):
    """Raised when enabled hardware output lacks a complete safe configuration."""


@dataclass(frozen=True)
class GpioConfig:
    enabled: bool
    gpiochip: str
    motor_dir_line: int
    start_line: int
    start_active_low: bool
    motor_direction_inverted: bool
    motor_pwm_chip: int
    motor_pwm_channel: int
    motor_pwm_frequency_hz: float
    motor_max_duty: float
    servo_pwm_chip: int
    servo_pwm_channel: int
    servo_pwm_frequency_hz: float
    servo_left_us: float
    servo_center_us: float
    servo_right_us: float
    watchdog_ms: int
    debounce_ms: int

    @classmethod
    def load(cls, path: Path) -> "GpioConfig":
        if not path.exists():
            return cls.safe_disabled()
        raw = json.loads(path.read_text(encoding="utf-8"))
        cfg = cls(
            enabled=bool(raw.get("enabled", False)),
            gpiochip=str(raw.get("gpiochip", "/dev/gpiochip0")),
            motor_dir_line=int(raw.get("motor_dir_line", -1)),
            start_line=int(raw.get("start_line", -1)),
            start_active_low=bool(raw.get("start_active_low", True)),
            motor_direction_inverted=bool(raw.get("motor_direction_inverted", False)),
            motor_pwm_chip=int(raw.get("motor_pwm_chip", -1)),
            motor_pwm_channel=int(raw.get("motor_pwm_channel", -1)),
            motor_pwm_frequency_hz=float(raw.get("motor_pwm_frequency_hz", 20000)),
            motor_max_duty=float(raw.get("motor_max_duty", 0.65)),
            servo_pwm_chip=int(raw.get("servo_pwm_chip", -1)),
            servo_pwm_channel=int(raw.get("servo_pwm_channel", -1)),
            servo_pwm_frequency_hz=float(raw.get("servo_pwm_frequency_hz", 50)),
            servo_left_us=float(raw.get("servo_left_us", 1100)),
            servo_center_us=float(raw.get("servo_center_us", 1500)),
            servo_right_us=float(raw.get("servo_right_us", 1900)),
            watchdog_ms=int(raw.get("watchdog_ms", 250)),
            debounce_ms=int(raw.get("debounce_ms", 60)),
        )
        cfg.validate()
        return cfg

    @classmethod
    def safe_disabled(cls) -> "GpioConfig":
        return cls(
            enabled=False,
            gpiochip="/dev/gpiochip0",
            motor_dir_line=-1,
            start_line=-1,
            start_active_low=True,
            motor_direction_inverted=False,
            motor_pwm_chip=-1,
            motor_pwm_channel=-1,
            motor_pwm_frequency_hz=20000,
            motor_max_duty=0.65,
            servo_pwm_chip=-1,
            servo_pwm_channel=-1,
            servo_pwm_frequency_hz=50,
            servo_left_us=1100,
            servo_center_us=1500,
            servo_right_us=1900,
            watchdog_ms=250,
            debounce_ms=60,
        )

    def validate(self) -> None:
        if not 0.0 < self.motor_max_duty <= 1.0:
            raise GpioConfigurationError("motor_max_duty must be in (0, 1]")
        if not 100 <= self.watchdog_ms <= 1000:
            raise GpioConfigurationError("watchdog_ms must be in 100..1000")
        if not (
            500 <= self.servo_left_us < self.servo_center_us < self.servo_right_us <= 2500
        ):
            raise GpioConfigurationError(
                "servo pulse order must be 500 <= left < centre < right <= 2500 us"
            )
        if self.enabled:
            required = {
                "motor_dir_line": self.motor_dir_line,
                "start_line": self.start_line,
                "motor_pwm_chip": self.motor_pwm_chip,
                "motor_pwm_channel": self.motor_pwm_channel,
                "servo_pwm_chip": self.servo_pwm_chip,
                "servo_pwm_channel": self.servo_pwm_channel,
            }
            missing = [name for name, value in required.items() if value < 0]
            if missing:
                raise GpioConfigurationError(
                    "enabled=true but these mappings are unset: " + ", ".join(missing)
                )
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

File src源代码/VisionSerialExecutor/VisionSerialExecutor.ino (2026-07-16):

/*
 * 2026 WRO Future Engineers - Vision Serial Executor
 * 2026 WRO未来工程师——视觉串口执行端
 *
 * Team / 队伍: BONA SONORITY SCHOOL NANJING / 南京博颂学校
 * Target / 目标: Arduino UNO + PWM/DIR motor-driver interface
 *
 * This program is the competition-candidate lower-level controller for the
 * current vision-only architecture. It accepts ASCII lines from the Orange Pi:
 *
 *   steer,speed\n
 *
 * Both values must be integers in -100..100. The vehicle is stopped at power-up,
 * requires a physical button press, ignores malformed messages, limits actuator
 * outputs, and enters a local fail-safe after 250 ms without a valid command.
 * A fail-safe can be cleared only with another physical button press; a fresh
 * command received after that press is required before motion resumes.
 *
 * 本程序是当前纯视觉架构的比赛候选底层控制器。Orange Pi以ASCII文本行
 * “steer,speed\n”发送命令，两项都必须是-100..100内的整数。车辆上电默认
 * 停止，必须按下物理按钮才允许接收行驶命令；畸形消息会被忽略，执行输出
 * 受到限幅，250 ms内没有合法新命令即进入本地安全停车。故障后必须再次按
 * 物理按钮，并在按键后收到新命令，车辆才可能恢复运动。
 *
 * IMPORTANT / 重要:
 * - Verify motor-driver electrical compatibility before connecting hardware.
 * - Confirm steering sign, motor direction and mechanical servo limits with the
 *   wheels lifted. Change the constants below only from measured results.
 * - This interface is PWM + DIR. A dual-PWM driver needs a different output layer.
 * - 接线前必须核对电机驱动器电气接口；必须架空车轮确认转向正负、电机方向
 *   和舵机机械极限。此版本为PWM+DIR接口，双PWM驱动器不能直接使用。
 */

#include <Servo.h>
#include <stdlib.h>

// Current documented candidate pin map / 当前文档候选引脚
const uint8_t PIN_SERVO = 2;
const uint8_t PIN_MOTOR_PWM = 6;
const uint8_t PIN_MOTOR_DIR = 7;
const uint8_t PIN_START_BUTTON = 8;  // Normally open to GND / 常开按钮接GND

// Conservative initial limits; replace only after lifted-wheel calibration.
// 保守初始限位；仅在架空标定后依据实测修改。
const int SERVO_LEFT_DEG = 45;
const int SERVO_CENTER_DEG = 90;
const int SERVO_RIGHT_DEG = 135;
const uint8_t MAX_MOTOR_PWM = 170;  // 67% of 255 during integration tests

const unsigned long COMMAND_TIMEOUT_MS = 250;
const unsigned long BUTTON_DEBOUNCE_MS = 35;
const unsigned long STATUS_INTERVAL_MS = 500;
const uint8_t RX_BUFFER_SIZE = 24;

enum RobotState : uint8_t {
  WAIT_START = 0,
  VISION_DRIVE = 1,
  COMMS_FAILSAFE = 2
};

Servo steeringServo;
RobotState state = WAIT_START;

char rxBuffer[RX_BUFFER_SIZE];
uint8_t rxLength = 0;
bool rxOverflow = false;

int targetSteer = 0;
int targetSpeed = 0;
bool freshCommandSinceArm = false;
unsigned long lastValidCommandMs = 0;
unsigned long lastStatusMs = 0;

bool lastButtonReading = HIGH;
bool stableButtonState = HIGH;
unsigned long lastButtonChangeMs = 0;

void setSteeringLogical(int command) {
  command = constrain(command, -100, 100);
  int angle;
  if (command < 0) {
    angle = map(command, -100, 0, SERVO_LEFT_DEG, SERVO_CENTER_DEG);
  } else {
    angle = map(command, 0, 100, SERVO_CENTER_DEG, SERVO_RIGHT_DEG);
  }
  steeringServo.write(constrain(angle, SERVO_LEFT_DEG, SERVO_RIGHT_DEG));
}

void setMotorLogical(int command) {
  command = constrain(command, -100, 100);
  const bool forward = command >= 0;
  const uint8_t pwm = (uint8_t)map(abs(command), 0, 100, 0, MAX_MOTOR_PWM);
  digitalWrite(PIN_MOTOR_DIR, forward ? HIGH : LOW);
  analogWrite(PIN_MOTOR_PWM, pwm);
}

void stopActuators() {
  analogWrite(PIN_MOTOR_PWM, 0);
  setSteeringLogical(0);
  targetSteer = 0;
  targetSpeed = 0;
}

void enterWaitStart() {
  stopActuators();
  freshCommandSinceArm = false;
  state = WAIT_START;
  Serial.println(F("STATE,WAIT_START"));
}

void enterFailsafe() {
  stopActuators();
  freshCommandSinceArm = false;
  state = COMMS_FAILSAFE;
  Serial.println(F("STATE,COMMS_FAILSAFE"));
}

bool parseIntegerToken(const char *text, int &value) {
  if (text == NULL || *text == '\0') return false;
  char *endPointer = NULL;
  const long parsed = strtol(text, &endPointer, 10);
  if (*endPointer != '\0' || parsed < -100 || parsed > 100) return false;
  value = (int)parsed;
  return true;
}

bool parseCommandLine(char *line, int &steerOut, int &speedOut) {
  char *comma = strchr(line, ',');
  if (comma == NULL || strchr(comma + 1, ',') != NULL) return false;
  *comma = '\0';
  return parseIntegerToken(line, steerOut) && parseIntegerToken(comma + 1, speedOut);
}

void handleCompleteLine() {
  rxBuffer[rxLength] = '\0';
  int parsedSteer = 0;
  int parsedSpeed = 0;

  if (!rxOverflow && parseCommandLine(rxBuffer, parsedSteer, parsedSpeed)) {
    // Commands received before physical arming are deliberately discarded.
    // 物理启动前收到的命令会被主动丢弃，防止旧命令触发车辆。
    if (state == VISION_DRIVE) {
      targetSteer = parsedSteer;
      targetSpeed = parsedSpeed;
      lastValidCommandMs = millis();
      freshCommandSinceArm = true;
    }
  }

  rxLength = 0;
  rxOverflow = false;
}

void readSerialNonBlocking() {
  while (Serial.available() > 0) {
    const char incoming = (char)Serial.read();
    if (incoming == '\n') {
      handleCompleteLine();
    } else if (incoming != '\r') {
      if (rxLength < RX_BUFFER_SIZE - 1) {
        rxBuffer[rxLength++] = incoming;
      } else {
        rxOverflow = true;
      }
    }
  }
}

bool startButtonPressed() {
  const bool reading = digitalRead(PIN_START_BUTTON);
  if (reading != lastButtonReading) {
    lastButtonReading = reading;
    lastButtonChangeMs = millis();
  }

  if ((millis() - lastButtonChangeMs) >= BUTTON_DEBOUNCE_MS &&
      stableButtonState != reading) {
    stableButtonState = reading;
    return stableButtonState == LOW;
  }
  return false;
}

void handleStartButton() {
  if (!startButtonPressed()) return;

  if (state == VISION_DRIVE) {
    // The same button acts as a local stop while running.
    // 行驶中按同一按钮，立即回到停车等待状态。
    enterWaitStart();
  } else {
    stopActuators();
    freshCommandSinceArm = false;
    lastValidCommandMs = millis();
    state = VISION_DRIVE;
    Serial.println(F("STATE,VISION_DRIVE_ARMED"));
  }
}

void updateStateMachine() {
  if (state == WAIT_START || state == COMMS_FAILSAFE) {
    stopActuators();
    return;
  }

  const unsigned long commandAgeMs = millis() - lastValidCommandMs;
  if (!freshCommandSinceArm) {
    stopActuators();
    if (commandAgeMs > COMMAND_TIMEOUT_MS) enterFailsafe();
    return;
  }

  if (commandAgeMs > COMMAND_TIMEOUT_MS) {
    enterFailsafe();
    return;
  }

  setSteeringLogical(targetSteer);
  setMotorLogical(targetSpeed);
}

void printStatusPeriodically() {
  if (millis() - lastStatusMs < STATUS_INTERVAL_MS) return;
  lastStatusMs = millis();
  Serial.print(F("STATUS,"));
  Serial.print((int)state);
  Serial.print(',');
  Serial.print(targetSteer);
  Serial.print(',');
  Serial.print(targetSpeed);
  Serial.print(',');
  if (state == VISION_DRIVE && freshCommandSinceArm) {
    Serial.println(millis() - lastValidCommandMs);
  } else {
    Serial.println(F("NA"));
  }
}
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

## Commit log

2026-05-30 更新团队照片
2026-06-06 代码
    更新基础代码
2026-07-14 7.14
    更新程序细节等内容
    [HSP94182层板.dxf]
2026-07-14 更新主程序
2026-07-16 docs: build complete project landing page and document vision code
2026-07-16 更新内容
    更新图片
2026-07-16 更新视频
    更新视频
2026-07-16 更新
    更新
2026-07-16 更新图片
    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
2026-07-16 介绍
    更新介绍
